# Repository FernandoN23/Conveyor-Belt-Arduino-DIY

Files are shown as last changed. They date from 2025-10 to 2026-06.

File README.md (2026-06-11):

# Conveyor Belt Arduino DIY V2🏗️🤖






*Author: Fernando Navarrete* ✍️

---

## English Version 🇺🇸

### 🌟 Project Overview
Welcome to the **Conveyor Belt Arduino DIY** master repository! This project details the multidisciplinary design, prototyping, and automation of an **Automatic Sorting Conveyor Belt** controlled by an Arduino microcontroller.

The machine scans physical objects inside a darkened chamber using a **TCS3200 (GY-31) Color Sensor**, maps raw optical readings into standard RGB values, and commands electromechanical actuators to split the materials into different receiving bins.

---

### 🚀 What's New in Version 2 (V2 Updates)
The system has been completely overhauled from the previous V1 baseline to meet the technical requirements of **Mechatronics Challenge 2**. 

* **Ergonomic CAD Redesign:** Structural components were re-engineered for simpler, faster physical assembly, optimized alignment tolerances, and enhanced overall rigidity.
* **Custom PCB Centralization:** Point-to-point breadboard/jumper wiring was eliminated. A dedicated green PCB with high-contrast yellow silkscreen was engineered in EasyEDA, introducing an **LM2596 DC-DC Buck Regulator** for 5V stability, a **470µF filter capacitor** to buffer servo spikes, and modular XH2.54 connector rails.
* **Worm Gear Power Transmission:** The V1 DC motor was upgraded to a high-torque **NEMA 17 Stepper Motor** driven by an **EasyDriver A3967**. Power transfer is achieved via an integrated printed worm screw (*tornillo helicoidal*) and a custom gear pulley, preventing unintended belt slides via mechanical irreversibility.
* **Innovative TPU Timing Belt:** Implemented a lightweight, continuous V-trapezoidal timing belt printed locally in two separate flexible **TPU** parts and bonded with high-strength cyanoacrylate. Testing validated that this bond does not compromise tensile strength, allowing a 100% printed internal drive loop (leaving only the clear acrylic side walls for structural visibility).

#### 🔮 Future Enhancements & Roadmap
* **Electrical Noise Isolation:** Reroute the PCB traces into a V3 revision with a dedicated, star-grounded row of free `GND` headers to isolate stepper power returns from the sensitive Arduino logic lines.
* **Industrial Belt Upgrade:** Transition from the current custom-printed TPU belt to an off-the-shelf industrial síncrona timing belt to enhance continuous operation lifespans.

---

## Versión en Español 🇪🇸

### 🌟 Resumen del Proyecto
¡Bienvenido al repositorio maestro **Conveyor Belt Arduino DIY**! Este proyecto detalla el diseño multidisciplinario, prototipado y automatización de una **Cinta Transportadora Clasificadora Automática** controlada por un microcontrolador Arduino.

El sistema escanea objetos físicos dentro de una cámara oscura mediante un **Sensor de Color TCS3200 (GY-31)**, mapea las lecturas ópticas crudas a valores RGB estándar y comanda actuadores electromecánicos para desviar las piezas hacia sus respectivos depósitos de clasificación.

---

### 🚀 Novedades de la Versión 2 (Actualizaciones V2)
El sistema ha sido completamente rediseñado desde la base de la versión V1 para cumplir con los exigentes requerimientos técnicos del **Desafío 2 de Mecatrónica**.

* **Rediseño Mecánico CAD:** Componentes estructurales optimizados para lograr un ensamblaje físico más simple, rápido y ergonómico, mejorando las tolerancias de alineación y la rigidez general del chasis.
* **Implementación de PCB Personalizada:** Se eliminó por completo el desorden de cables flotantes de la V1. Se diseñó una PCB verde con serigrafía amarilla en EasyEDA, incorporando un regulador **Buck DC-DC LM2596** para estabilizar el riel de 5V, un **condensador de filtro de 470µF** para absorber picos de los servos y filas de conectores modulares XH2.54 de conexión rápida.
* **Transmisión por Tornillo Sin Fin:** El motor DC convencional fue reemplazado por un **Motor Paso a Paso NEMA 17** de alto torque controlado por un driver **EasyDriver A3967**. La potencia se transmite mediante un tornillo helicoidal impreso y una polea corona engranada, dotando al sistema de irreversibilidad mecánica para evitar deslizamientos por inercia.
* **Correa Continua de TPU Impresa:** Se implementó una correa delgada trapezoidal tipo *timing belt* impresa localmente en dos partes de **TPU** flexible, unidas firmemente con cianoacrilato (*gotita*). Las pruebas de laboratorio demostraron que esta unión no compromete la resistencia a la tracción (aguanta una carga considerable), logrando que casi todo el mecanismo sea impreso (excepto las paredes de acrílico claro).

#### 🔮 Mejoras a Futuro y Hoja de Ruta
* **Aislamiento de Ruido Eléctrico:** Reconfigurar el ruteo de pistas para una revisión V3 incorporando filas de pines `GND` libres en una distribución de tierra en estrella, aislando los retornos de potencia del motor de las líneas lógicas del Arduino.
* **Correa Industrial Síncrona:** Reemplazar a futuro la correa de TPU impresa por una correa síncrona industrial comercial (adquirida externamente) para maximizar los ciclos de trabajo continuo.

---

## 📚 Documentation & Modules / Documentación y Módulos

Explore the directories below for detailed technical documentation on the current V2 standard and legacy V1 history.
*Explora los directorios a continuación para revisar la documentación técnica de la versión V2 actual y el historial heredado de la V1.*

| Module / Módulo | Description / Descripción |
| :--- | :--- |
| **📦 [Bill of Materials (BOM) / Lista de Materiales](./Conveyor-Belt-Arduino-V2/BOM%20v2/README.md)** | **V2 Purchase List & Printed Weights.** <br>Complete catalog of current hardware (NEMA 17, EasyDriver, LM2596, custom PCB) and empty weight fields for 3D printed parts.<br>---<br>**Lista de Compra y Pesos V2.**<br>Catálogo completo de hardware actual (NEMA 17, EasyDriver, LM2596, PCB) y espacios para rellenar los gramos de las piezas impresas. |
| **📐 [CAD Design Files / Archivos de Diseño CAD](./Conveyor-Belt-Arduino-V2/CAD%20v2/README.md)** | **Source Models (Fusion 360 & STEP V2).** <br>Download the digital twin organized into `/Electronic Parts`, `/Mechanic Parts`, and custom `/Parts` sub-folders.<br>---<br>**Modelos Fuente (Fusion 360 y STEP V2).**<br>Descarga el gemelo digital organizado en subcarpetas de componentes electrónicos, mecánicos y piezas personalizadas. |
| **🔦 [Acrylic Manufacturing / Manufactura de Acrílico](./Conveyor-Belt-Arduino-V1/Acrylic%20Wall%20Manufacturing/README.md)** | **Laser Cutting Files (Legacy/Reference).** <br>Production layouts (`.dxf`, `.beam`) for the transparent 4mm side walls critical for housing structural integrity.<br>---<br>**Archivos de Corte Láser (Referencia).**<br>Planos de producción (`.dxf`, `.beam`) para las paredes laterales de acrílico transparente de 4mm, críticas para la estructura. |
| **⚡ [Electronics & Wiring / Cableado y Electrónica](./Conveyor-Belt-Arduino-V2/Electronics%20v2/README.md)** | **PCB Schematics & Gerber Layouts.** <br>Contains the EasyEDA schematic sheets, trace distribution dimensions (0.4mm/0.6mm), and `Gerber_Files_V2.zip` production archives.<br>---<br>**Esquemas de PCB y Archivos Gerber.**<br>Contiene los esquemas de EasyEDA, anchos de pista lógicos/potencia (0.4mm/0.6mm) y el comprimido de producción `Gerber_Files_V2.zip`. |
| **💻 [Software & Logic / Programación y Lógica](./Conveyor-Belt-Arduino-V2/Code%20v2/README.md)** | **AccelStepper Firmware V2.** <br>Source code (`.ino`) incorporating `AccelStepper` non-blocking ramps, sensor mapping functions, and hardware protection angle clamps.<br>---<br>**Firmware AccelStepper V2.**<br>Código fuente (`.ino`) que incorpora control de rampas no bloqueantes con `AccelStepper`, mapeo del sensor y límites de seguridad angular. |
| **📸 [Multimedia Gallery / Galería Multimedia](./Multimedia/README.md)** | **Renders & Visuals.** <br>High-quality digital Twin renders, workbench photos, and operational video reels of the final sorting system.<br>---<br>**Renders y Visuales.**<br>Renders de alta calidad del gemelo digital, capturas del banco de pruebas y videos de operación del sistema clasificador. |

---

## 🎓 Acknowledgments / Agradecimientos

This project was made possible thanks to the academic support and specialized fabrication facilities provided by the **University of Chile**.

*Este proyecto fue posible gracias al apoyo académico y las instalaciones de fabricación especializadas provistas por la **Universidad de Chile**.*

| Institution / Institución | Contribution / Contribución |
| :---: | :--- |
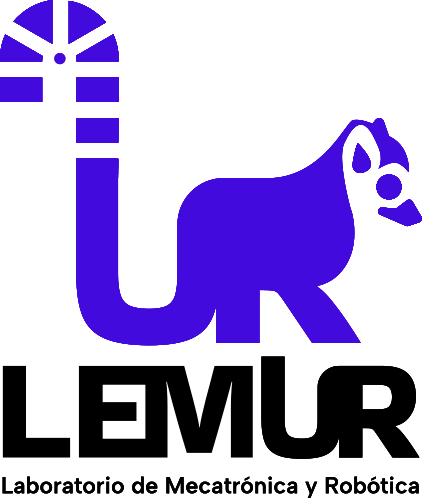
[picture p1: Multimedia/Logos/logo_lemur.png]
LEMUR Logo
|  | **LEMUR (Laboratorio de Ingeniería Mecatrónica y Robótica)**<br>For providing the specialized engineering workspace, FDM 3D printers, and test instrumentation required for the belt validation.<br>*(Por proveer el espacio de ingeniería, impresoras 3D FDM e instrumentación de prueba necesaria para la validación de la correa).* |
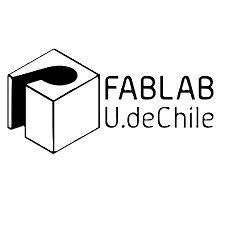
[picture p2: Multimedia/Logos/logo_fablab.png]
FabLab Logo
|  | **FABLAB U. de Chile**<br>For their technical manufacturing advisory and access to computer-controlled machinery, specifically the Beambox Series Pro laser cutter.<br>*(Por su asesoría técnica en manufactura y el uso de maquinaria CNC, principalmente la cortadora láser Beambox Series Pro).* |

---
*Open Source Project - Mechatronics V2 Revision (2026)*

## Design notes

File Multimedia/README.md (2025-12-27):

# Conveyor Belt Arduino DIY - Multimedia Gallery 📸🎬

*Author: Fernando Navarrete* ✍️

## English Version 🇺🇸

Welcome to the **Multimedia** directory! 🖼️

This folder serves as the visual documentation hub for the **Sorting Conveyor Belt** project. Here you will find CAD renders, assembly diagrams, and in future updates, real-world photos and videos of the working prototype.

### 📂 Folder Structure

The visual assets are organized by project iteration:

```text
Multimedia
├── 📂 Logos
├── 📂 V1
│   ├── 📂 as_built  <-- Final conveyor belt multimedia
│   ├── 🖼️ Ensamble Correa Transportadora ISO.png
│   ├── 🖼️ Ensamble Correa Transportadora Oruga Interior.png
│   ├── ... (Other render views)
│   └── 🖼️ Ensamble_ISO_Black_background.png
└── 📝 README.md                    <-- (Documentation) You are here

```

---

### 🏗️ Version 1 (V1) - CAD Design

This section documents the first iteration of the mechanism. The images below represent the **3D Modeling and Rendering** phase, used to validate geometry, mechanical tolerances, and component layout before physical manufacturing.

> **Note:** These images represent the virtual environment. Photos of the physical assembly will be added in a later stage inside a `/Real_Photos` directory.

#### 🌟 Hero View (Studio Render)

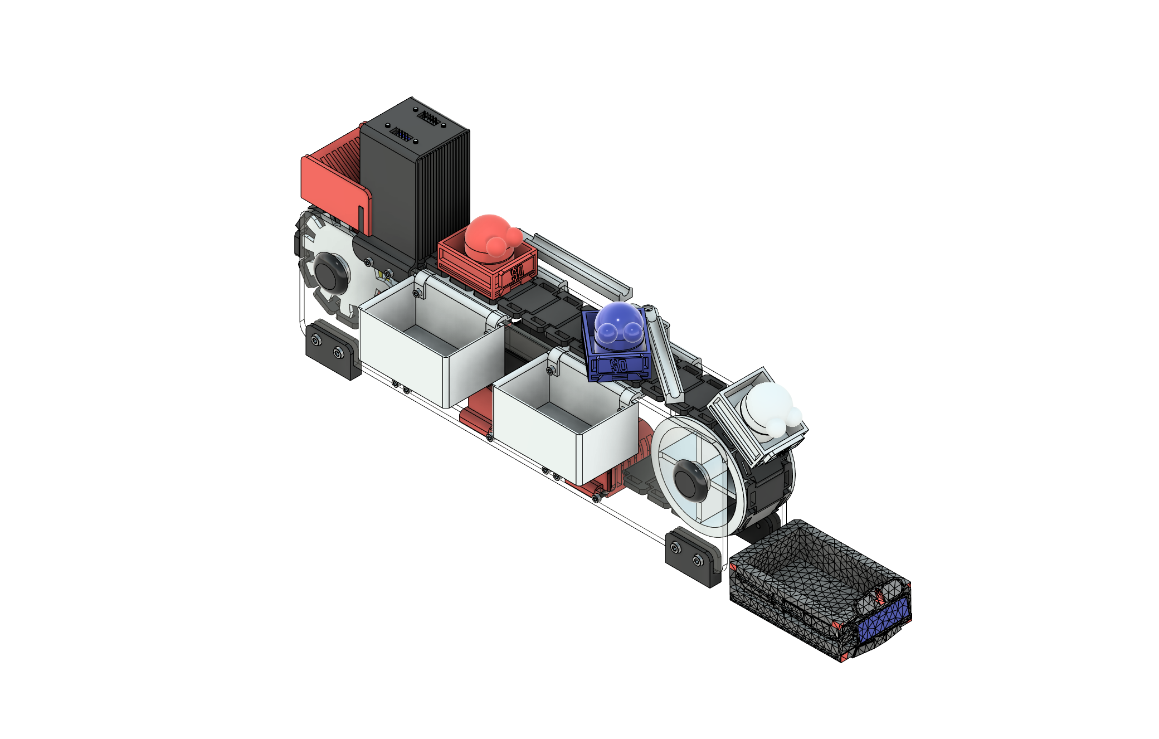
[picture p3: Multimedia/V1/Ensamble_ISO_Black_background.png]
Vista Hero


#### 📐 Technical Views & Assembly

Below is a gallery of different perspectives of the mechanical design, including isometric, top, and profile views to assist in understanding the structure.

| Isométrica General | Isométrica Alternativa |
| :---: | :---: |
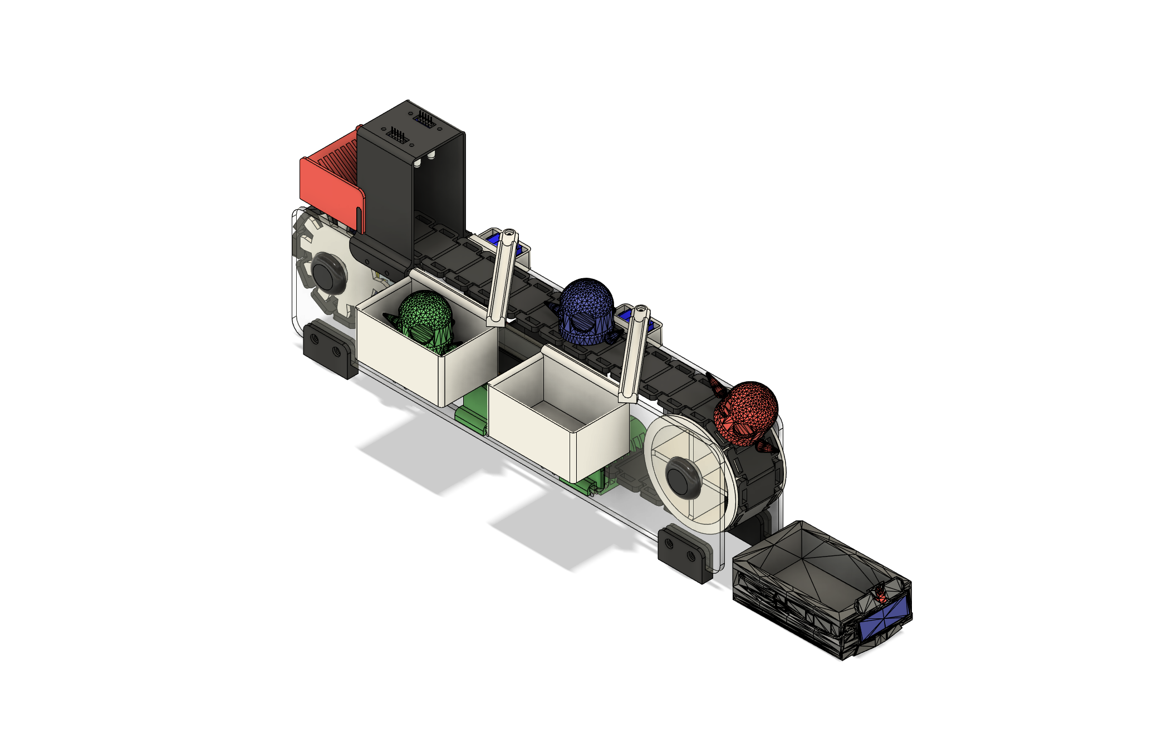
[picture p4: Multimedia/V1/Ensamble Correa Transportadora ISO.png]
Iso 1
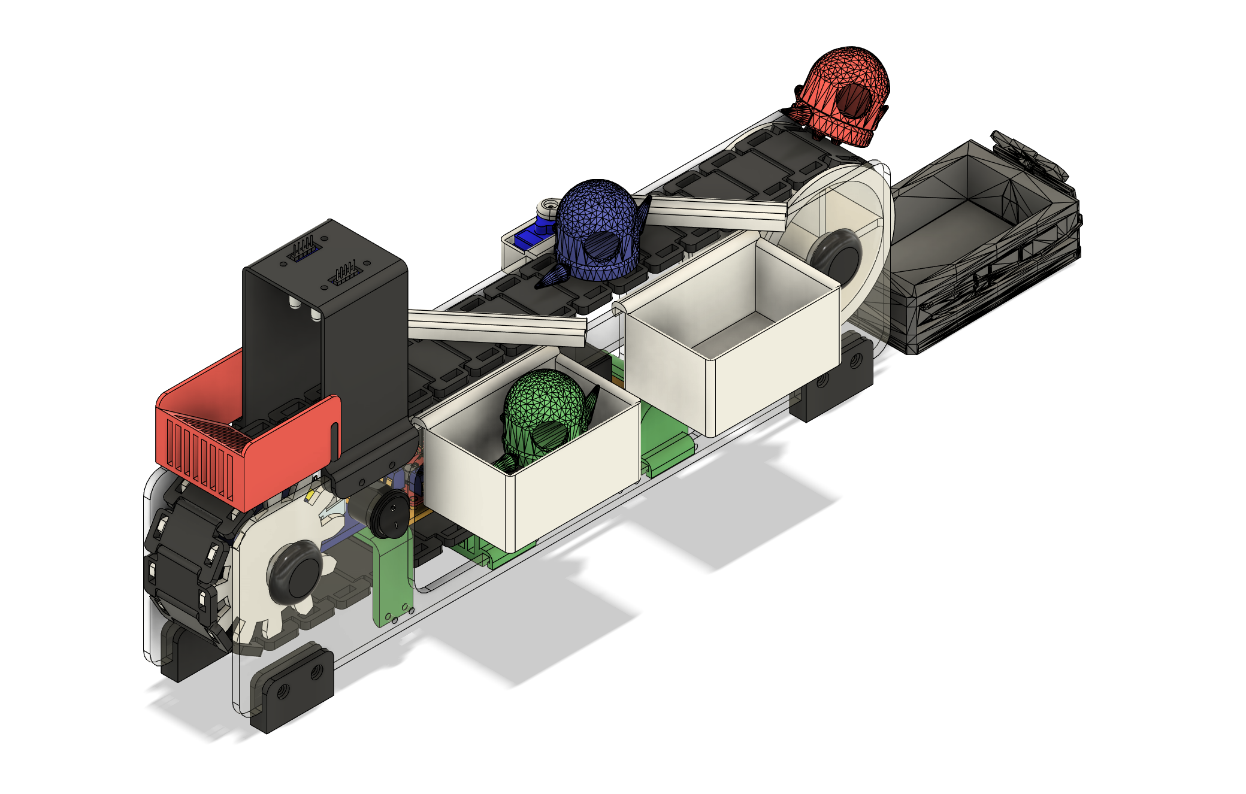
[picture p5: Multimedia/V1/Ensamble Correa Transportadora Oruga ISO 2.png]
Iso 2
|  |  |

| Vista de Planta (Superior) | Vista Lateral (Perfil) |
| :---: | :---: |
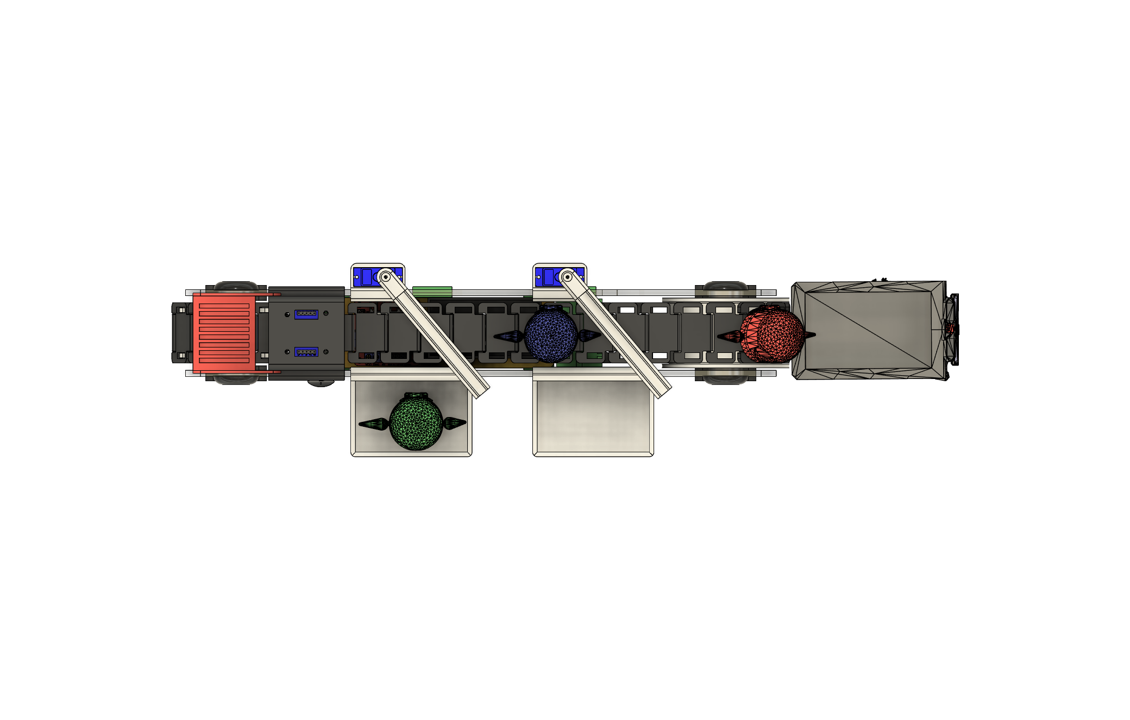
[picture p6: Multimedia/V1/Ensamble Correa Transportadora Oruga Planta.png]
Planta
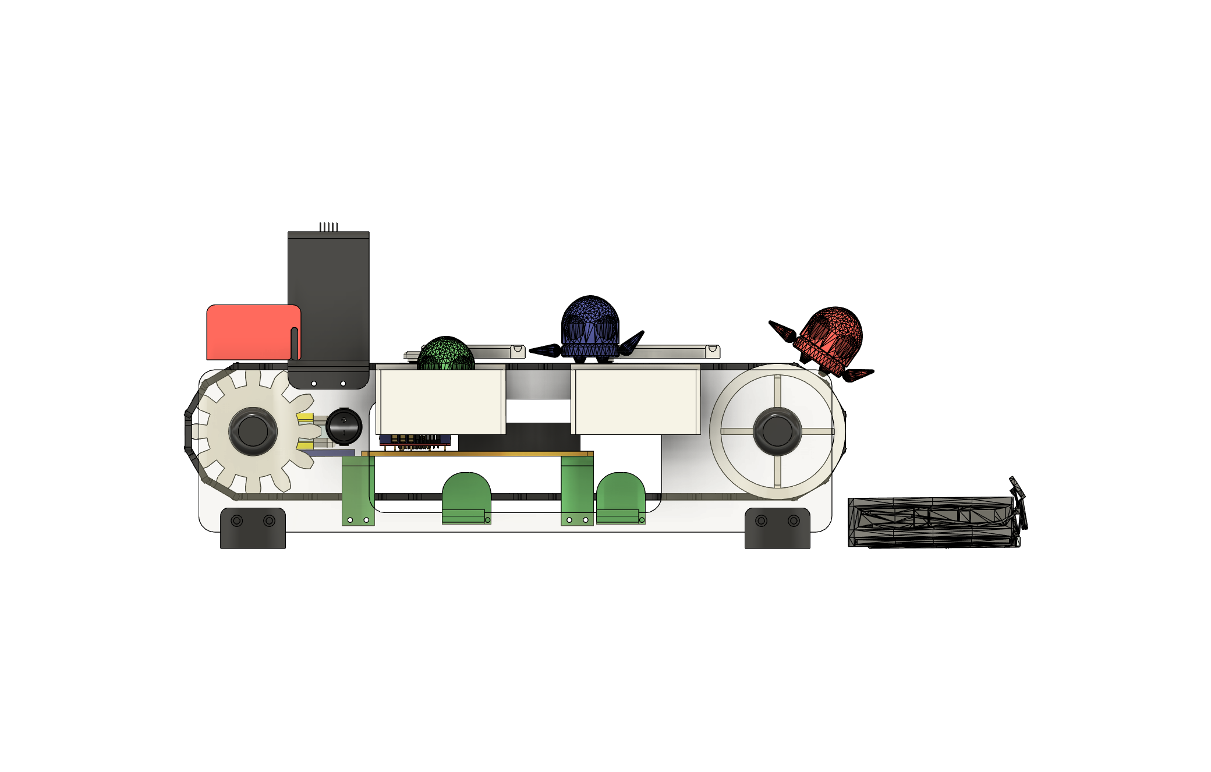
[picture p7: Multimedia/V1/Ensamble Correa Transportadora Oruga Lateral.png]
Lateral
|  |  |

#### ⚙️ Mechanical Detail: Internal Track System

Focus on the internal arrangement of pulleys and transmission.

| Internal Mechanism |
| --- |
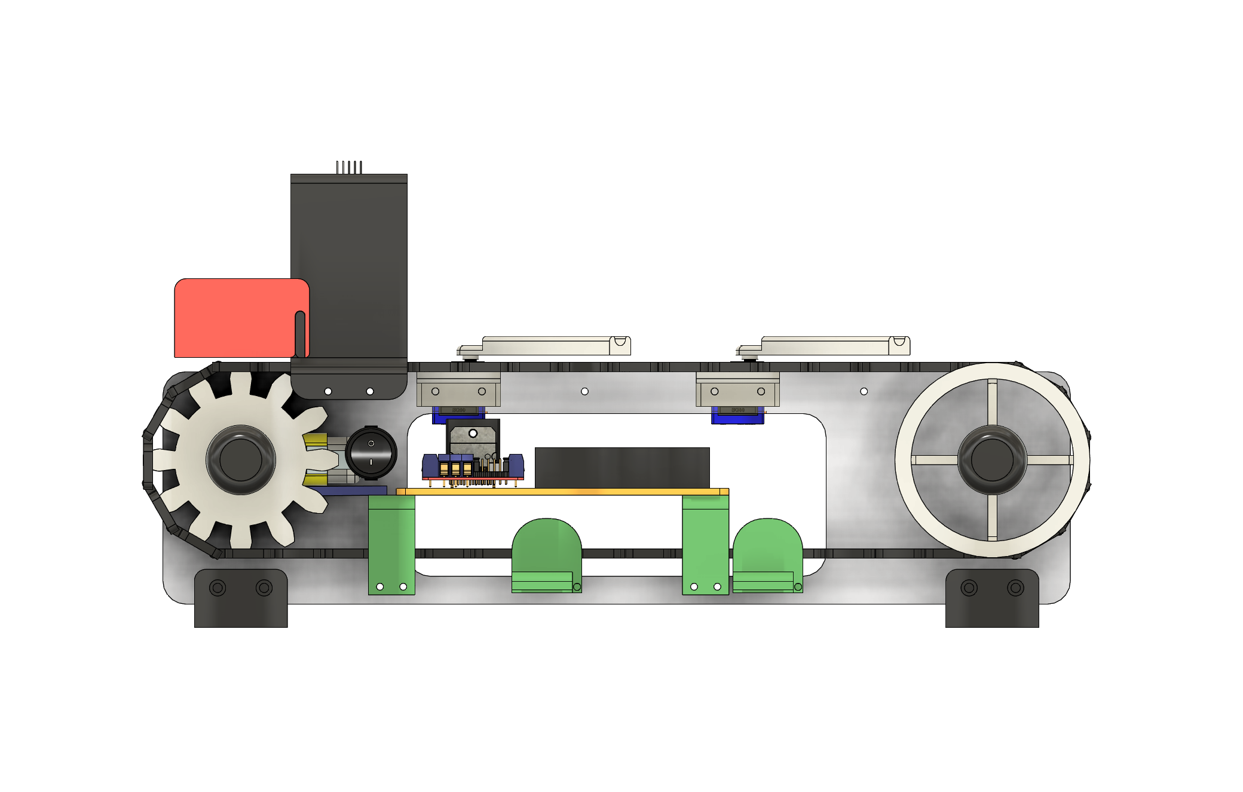
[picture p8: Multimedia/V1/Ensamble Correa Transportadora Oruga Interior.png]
Interior
|  |

> **⚠️ Mechanical Note on Tolerances:**
> Due to the necessary design clearances (tolerances) in the CAD model, **belt tensioners are not shown in their active operational state** in these renders.
> However, for the physical assembly, tensioners are **mandatory** to ensure proper friction and movement of the belt.

---

## Versión en Español 🇪🇸

*Autor: Fernando Navarrete* ✍️

¡Bienvenido al directorio **Multimedia**! 🖼️

Esta carpeta sirve como el centro de documentación visual para el proyecto de la **Cinta Transportadora Clasificadora**. Aquí encontrarás renders del diseño, diagramas de ensamblaje y, en futuras actualizaciones, fotografías reales y videos del prototipo en funcionamiento.

### 📂 Estructura de Carpetas

Los recursos visuales están organizados por iteración del proyecto:

```text
Multimedia
├── 📂 Logos
├── 📂 V1
│   ├── 📂 as_built  <-- Multimedia final correa transportadora
│   ├── 🖼️ Ensamble Correa Transportadora ISO.png
│   ├── 🖼️ Ensamble Correa Transportadora Oruga Interior.png
│   ├── ... (Otras vistas renderizadas)
│   └── 🖼️ Ensamble_ISO_Black_background.png
└── 📝 README.md                    <-- (Documentación) Estás aquí

```

---

### 🏗️ Versión 1 (V1) - Diseño CAD

Esta sección documenta la primera iteración del mecanismo. Las imágenes presentadas a continuación corresponden a la fase de **Modelado 3D y Renderizado**, utilizadas para validar la geometría, las tolerancias mecánicas y la disposición de componentes antes de la manufactura física.

> **Nota:** Estas imágenes representan el entorno virtual. Las fotografías del ensamblaje físico se añadirán en una etapa posterior dentro de un directorio `/Real_Photos`.

#### 🌟 Vista Principal (Render de Estudio)

Vista Hero

#### 📐 Vistas Técnicas y de Ensamblaje

A continuación se presenta una galería con diferentes perspectivas del diseño mecánico, incluyendo vistas isométricas, de planta y de perfil para facilitar la comprensión de la estructura.

| Isométrica General | Isométrica Alternativa |
| :---: | :---: |
| Iso 1 | Iso 2 |

| Vista de Planta (Superior) | Vista Lateral (Perfil) |
| :---: | :---: |
| Planta | Lateral |

#### ⚙️ Detalle Mecánico: Sistema de Oruga Interior

Enfoque en la disposición interna de poleas y transmisión.

| Mecanismo Interno |
| --- |
| Interior |

> **⚠️ Nota Mecánica sobre Tolerancias:**
> Debido a las holguras de diseño necesarias en el modelo CAD, **los tensores de la correa no se muestran en su estado operativo de tensión** en estos renders.
> Sin embargo, para el ensamblaje físico, los tensores son **obligatorios** para asegurar la fricción y el movimiento correcto de la banda.

---

## 🛠️ Fabrication & As-Built (V1) / Fabricación y Prototipo Real

**🇬🇧 English:**
This section showcases the **physical realization** of the project. These photos demonstrate the final assembly using 3D printed parts, acrylic supports, and the electronic integration.

**🇪🇸 Español:**
Esta sección muestra la **realización física** del proyecto. Estas fotos demuestran el ensamblaje final utilizando piezas impresas en 3D, soportes de acrílico y la integración electrónica.

### 📸 Final Assembly / Ensamblaje Final

| Front View / Vista Frontal | Side View / Vista Lateral |
| ----- | ----- |
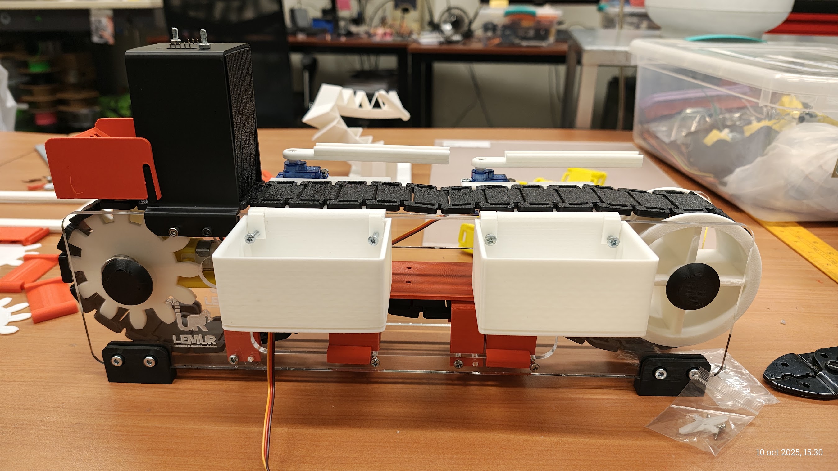
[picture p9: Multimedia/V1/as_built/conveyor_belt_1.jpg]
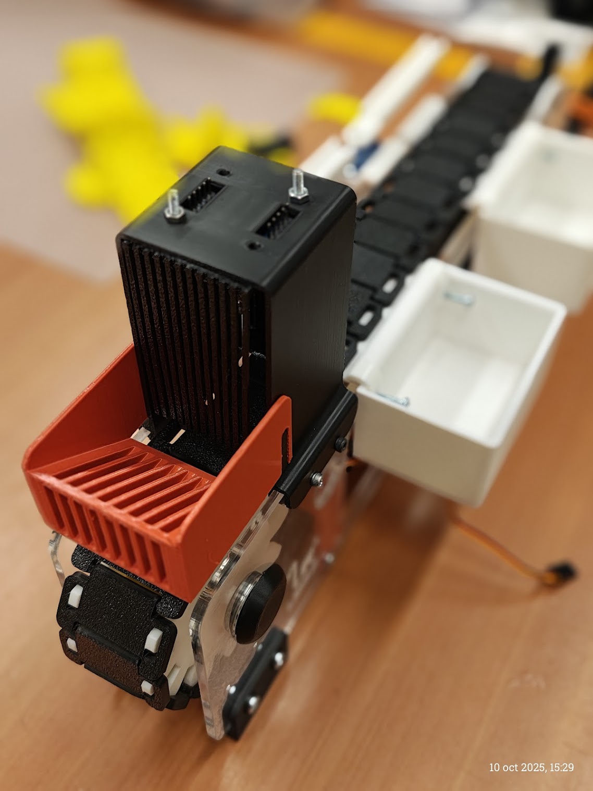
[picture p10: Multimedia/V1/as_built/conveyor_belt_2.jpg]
|  |  |

### 🔧 Fabrication Details / Detalles de Fabricación

| Fabrication / Fabricación | Acrylic Wall / Pared Acrílica | Release / Estreno |
| ----- | ----- | ----- |
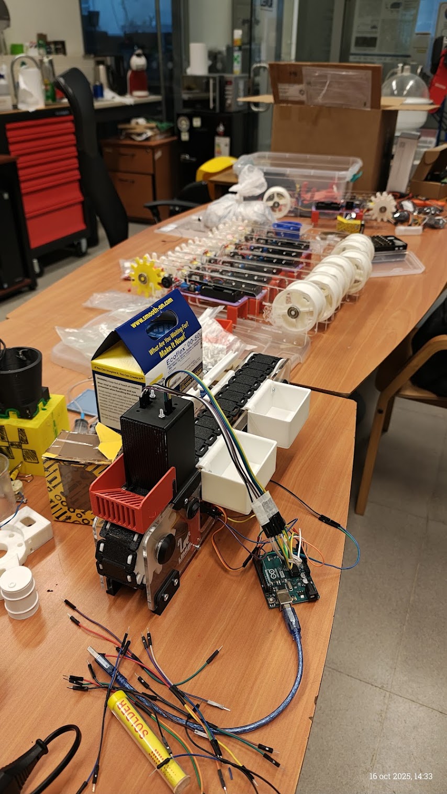
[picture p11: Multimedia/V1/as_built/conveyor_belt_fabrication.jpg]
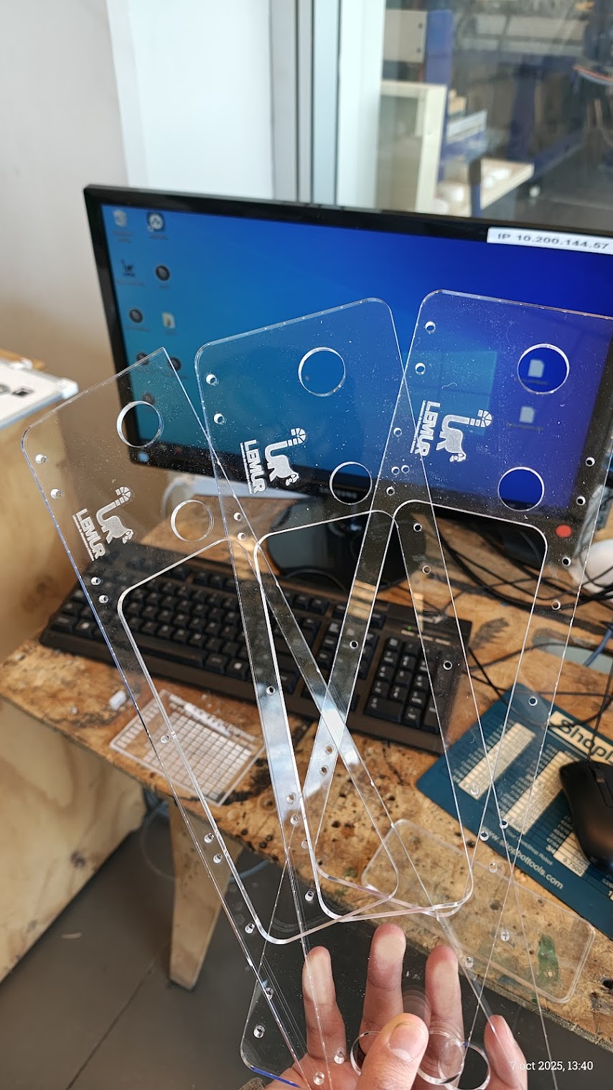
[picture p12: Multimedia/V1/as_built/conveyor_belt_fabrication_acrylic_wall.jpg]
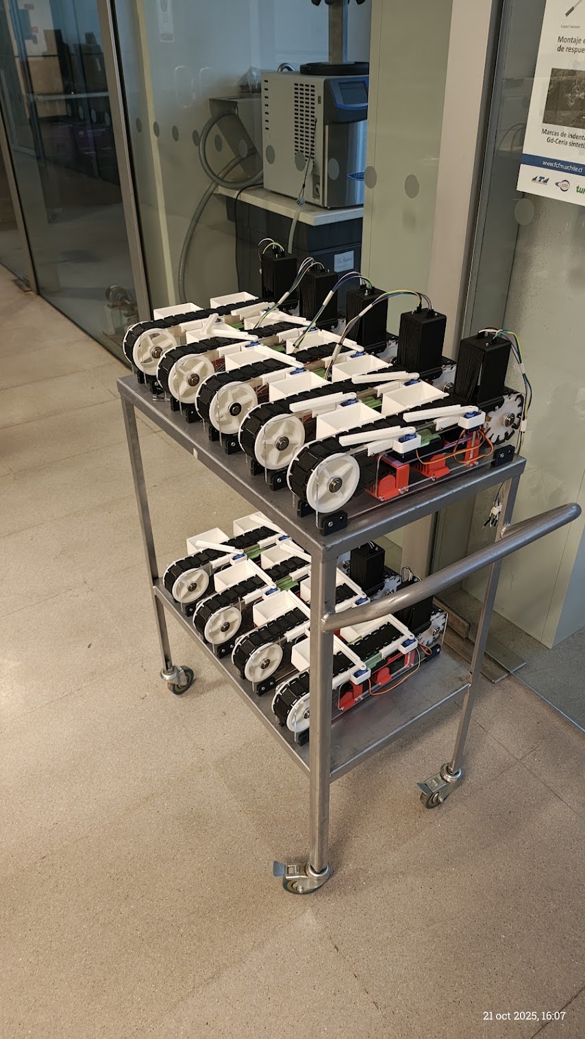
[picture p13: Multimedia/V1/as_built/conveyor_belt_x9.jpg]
|  |  |  |

---
*Happy Coding & Building!* 🚀

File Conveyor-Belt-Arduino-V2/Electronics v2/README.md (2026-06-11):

# Conveyor Belt Arduino DIY - Electronics & Wiring ⚡🔌

*Author: Fernando Navarrete* ✍️

## English Version 🇺🇸

Welcome to the **Electronics v2** directory! 🔋

This section covers the physical "nervous system" and custom circuit architecture of the **Sorting Conveyor Belt V2**. In this version, standard point-to-point jumper routing has been replaced by a **Custom Printed Circuit Board (PCB)** to enhance structural reliability, mitigate electromagnetic interference (EMI), and centralize modular connections.

### 📂 Available Manufacturing Files
Inside this directory, you will find the required hardware manufacturing and project files:
* 📁 **`Gerber_Files_V2.zip`**: Complete set of production photoplotter files in standard Gerber RS-274X format for physical CNC milling or external PCB manufacturing.
* 📦 **`Project_EasyEDA_V2.zip`**: Native source project package compatible with EasyEDA for hardware modifications, schematic tuning, and trace rerouting.

### 📜 Component Checklist
These are the core electronic components integrated into the custom board design:
* **Microcontroller:** Arduino Uno/Nano (The central logic processing unit).
* **Actuators:**
    * 1x NEMA 17 Stepper Motor (Main precise drive unit).
    * 1x EasyDriver A3967 Module (Microstepping driver).
    * 2x SG90 Servomotors (Sorting dynamic gates).
* **Sensors:**
    * 1x TCS3200 / GY-31 (RGB Color Sensor).
* **Power Regulation & Protection:**
    * 3x 18650 Li-Ion Batteries (~11.1V - 12.6V input power rail).
    * 1x LM2596 DC-DC Step-Down Buck Converter Module (Logic voltage regulator).
    * 1x 470µF Electrolytic Capacitor (De-coupling/filter layout element).
    * 1x SPST 2-Pin Toggle Switch.

---

### 🗺️ Electronic Diagram & PCB Specs

> **📄 VIEW DIAGRAM:**
> Please open the attached schematic PDF file **`Esquematico_Desafio_2_ME4250.pdf`** located in this folder to examine the component nets, footprint callouts, and internal routing sheets.

* **PCB Physical Spec Constraints:** * **Solder Mask color:** Industrial Green with high-contrast Yellow silkscreen labeling for clear pinout identification and project credits.
  * **Vias and Drill holes:** Standard logic size (0.254 mm / 10 mil).
  * **Trace Widths:** Standard signal/logic traces are routed at **0.4 mm**. Current-heavy Power traces (VCC, Motor outputs, and Regulator pins) are widened to **0.6 mm** to withstand step transients without heating.

---

### 🔌 Wiring Guide & Pinout Mapping

Ensure your modular cable harnesses (using XH2.54 terminal pins) match this hardware definition matrix embedded into the custom board layout:

| Component | Schematic Pin Label | Arduino Pin Connection | Description |
| :--- | :--- | :---: | :--- |
| **EasyDriver A3967** | STEP | **D2** | Step Pulse Command Signal |
| | DIR | **D3** | Direction Control Level |
| **TCS3200 (GY-31)** | S0, S1 | **A0, A1** | Output Frequency Scaling |
| | S2, S3 | **A2, A3** | Photodiode Color Array Selection |
| | OUT | **D4** | Frequency Pulse Width Input |
| **Servos (SG90)** | PWM_SG90_1 | **D9** | Gate 1 Actuator Control Signal |
| | PWM_SG90_2 | **D10** | Gate 2 Actuator Control Signal |

---

### ⚠️ Critical Engineering Design Note: Common Ground Anomalies

> **🛠️ POST-MORTEM HARDWARE OBSERVATION:**
> During the layout routing of the `Desafio_2_v2` schematic, a minor design discrepancy was introduced regarding the logic return path:
> * **The Issue:** The main `GND` network connection back to the Arduino microcontroler was bridged through a terminal pin assigned directly to the **LM2596 regulator block** instead of establishing a separate, noise-isolated digital ground pin on the main microcontroler header.
> * **Behavioral Impact:** Although electrical continuity is sustained globally across the negative terminal of the 18650 battery pack, heavy return currents from the stepper driver switching stages can couple electrical switching noise onto the sensitive analog/digital ground lines of the microcontroller.
> * **Future Iterations V3 Requirement:** Future engineering remakes must integrate a dedicated, independent row of free `GND` distribution headers linked via a clean star-ground layout geometry to safeguard signal integrity.

---

## Versión en Español 🇪🇸

*Autor: Fernando Navarrete* ✍️

¡Bienvenido al directorio **Electronics v2**! 🔋

Esta sección cubre el "sistema nervioso" físico y la arquitectura de circuitos de la **Cinta Transportadora Clasificadora V2**. En esta versión, el cableado por jumpers punto a punto ha sido reemplazado por una **Placa de Circuito Impreso (PCB) Personalizada** para mejorar la confiabilidad estructural, mitigar la interferencia electromagnética (EMI) y centralizar los acoples modulares.

### 📂 Archivos de Manufactura Disponibles
Dentro de este directorio, se encuentran los archivos necesarios para la fabricación del hardware:
* 📁 **`Gerber_Files_V2.zip`**: Conjunto de archivos de fotoploteo de producción en formato estándar Gerber RS-274X para el fresado CNC físico o manufactura externa de la PCB.
* 📦 **`Project_EasyEDA_V2.zip`**: Paquete nativo del proyecto compatible con EasyEDA para modificaciones de hardware, edición de esquemáticos y ruteo de pistas.

### 📜 Lista de Verificación de Componentes
Estos son los componentes electrónicos principales integrados en el diseño de la placa personalizada:
* **Microcontrolador:** Arduino Uno/Nano (Unidad de procesamiento lógico central).
* **Actuadores:**
    * 1x Motor Paso a Paso NEMA 17 (Unidad principal de tracción de precisión).
    * 1x Módulo Driver EasyDriver A3967 (Controlador de micropasos).
    * 2x Servomotores SG90 (Aletas dinámicas de clasificación).
* **Sensores:**
    * 1x TCS3200 / GY-31 (Sensor de Color RGB).
* **Regulación de Energía y Protección:**
    * 3x Baterías Li-Ion 18650 (Línea de potencia de entrada de ~11.1V - 12.6V).
    * 1x Regulador Convertidor Buck DC-DC Step-Down LM2596 (Regulador de voltaje lógico a 5V).
    * 1x Condensador Electrolítico de 470µF (Elemento de filtrado y desacople en la línea).
    * 1x Interruptor SPST de 2 pines.

---

### 🗺️ Diagrama Electrónico y Especificaciones de la PCB

> **📄 VER DIAGRAMA:**
> Por favor, abre el archivo PDF adjunto **`Esquematico_Desafio_2_ME4250.pdf`** en esta carpeta para examinar las redes de componentes, los encapsulados y los planos de ruteo interno.

* **Restricciones Técnicas de la PCB:** * **Color de Antisolder:** Verde industrial con serigrafía amarilla de alta definición para la identificación de pines, componentes y créditos del desarrollador.
  * **Vias y Perforaciones (Drills):** Tamaño estándar para señales lógicas (0.254 mm / 10 mil).
  * **Ancho de Pistas:** Las pistas estándar de señal lógica están ruteadas a **0.4 mm**. Las líneas de potencia que manejan alta corriente (VCC, salidas de motor y pines del regulador) se ensancharon a **0.6 mm** para soportar transitorios de corriente sin calentamiento del cobre.

---

### 🔌 Guía de Cableado y Mapa de Pines (Pinout)

Asegúrate de que los arneses de cables modulares (usando terminales XH2.54) coincidan con esta matriz de definición de hardware grabada en el diseño de la PCB:

| Componente | Etiqueta de Pin | Conexión Pin Arduino | Descripción |
| :--- | :--- | :---: | :--- |
| **EasyDriver A3967** | STEP | **D2** | Señal de Comando de Pulso de Paso |
| | DIR | **D3** | Nivel de Control de Dirección |
| **TCS3200 (GY-31)** | S0, S1 | **A0, A1** | Escalamiento de Frecuencia de Salida |
| | S2, S3 | **A2, A3** | Selección de Matriz de Fotodiodos de Color |
| | OUT | **D4** | Entrada de Ancho de Pulso de Frecuencia |
| **Servos (SG90)** | PWM_SG90_1 | **D9** | Señal de Control Actuador Aleta 1 |
| | PWM_SG90_2 | **D10** | Señal de Control Actuador Aleta 2 |

---

### ⚠️ Nota Crítica de Ingeniería: Anomalía de Tierra Común

> **🛠️ OBSERVACIÓN DE REVISIÓN DE HARDWARE:**
> Durante el ruteo de las pistas del esquemático `Desafio_2_v2`, se introdujo una leve discrepancia de diseño en el camino de retorno lógico:
> * **El Problema:** La conexión de la red principal de `GND` hacia el Arduino quedó vinculada a través de un pin de terminal destinado directamente al **bloque del regulador LM2596**, en lugar de establecerse en un pin de tierra digital independiente y aislado en el header principal del Arduino.
> * **Impacto Conductual:** Aunque existe continuidad eléctrica global con el terminal negativo del pack de baterías 18650, las corrientes de retorno intensas de las etapas de conmutación del motor paso a paso pueden acoplar ruido eléctrico en las líneas de tierra lógicas del microcontrolador.
> * **Requerimiento para Futuras Iteraciones V3:** Los próximos rediseños deben integrar obligatoriamente una fila dedicada e independiente de pines headers de distribución `GND` conectados mediante una geometría de tierra en estrella (*star ground*) para salvaguardar la integridad de la señal.

---
*Safety First: Always double-check polarity and visual traces before switching on! / ¡Seguridad ante todo: revisa siempre la polaridad y las pistas visuales antes de encender!* 👷⚡

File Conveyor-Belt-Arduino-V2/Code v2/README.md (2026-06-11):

# Conveyor Belt Arduino DIY - Software & Logic 💻⚙️

*Author: Fernando Navarrete* ✍️

## English Version 🇺🇸

Welcome to the **Code v2** directory! 🧠

This folder contains the firmware required to operate the **Sorting Conveyor Belt V2**. The system utilizes an **Arduino** microcontroller to manage the high-precision logic of object detection, RGB color mapping, and electromechanical actuation using a stepper motor and servo barriers.

### 📂 Folder Structure

Here is the organization of the source files included in this version:

```text
Code v2
├── 📂 Calibration_TCS3200
│   └── 📜 Calibration_TCS3200.ino       <-- (Utility) Calibrate sensor min/max pulse width
├── 📜 Conveyor_Belt_D2_Student.ino      <-- (Main) Production code for sorting & evaluation (Desafío 2 Mecatrónica)
└── 📝 README.md                         <-- (Documentation) You are here

```

### 🔌 Pinout & Wiring

> **⚡ Electronic Diagram:**
> For detailed schematics, custom PCB routing paths, and power regulation connections, please visit the **Electronics v2** module:
> 👉 **[Electronics v2 README](https://www.google.com/search?q=../Electronics%2520v2/README.md)**

Below is the specific hardware pin mapping defined in the production source code (`Conveyor_Belt_D2_Student.ino`). Ensure your physical custom board connections strictly match these definitions to prevent hardware issues:

| Component | Pin Function | Arduino Pin | Notes |
| --- | --- | --- | --- |
| **EasyDriver A3967** | STEP | **D2** | Step pulse signal (AccelStepper Control) |
|  | DIR | **D3** | Direction control signal |
| **TCS3200 (GY-31)** | S0 | **A0** | Frequency Scaling Selection |
|  | S1 | **A1** | Frequency Scaling Selection |
|  | S2 | **A2** | Color Photodiode Filter Select |
|  | S3 | **A3** | Color Photodiode Filter Select |
|  | OUT | **D4** | Signal pulse width input (`pulseIn`) |
| **Servos** | Servo 1 | **D9** | Sorts objects (Safety constrained) |
|  | Servo 2 | **D10** | Sorts objects (Safety constrained) |

> **⚠️ Dependencies:** You must install the `AccelStepper.h` library via the Arduino Library Manager, and ensure `Servo.h` is available in your IDE environment before compiling.

### 🛠️ Execution Pipeline & Methodology

#### 1. Sensor Ambient Calibration (`Calibration_TCS3200.ino`)

Before running the main execution logic, you must determine the hardware frequency responses under your specific ambient light environment:

1. Upload `Calibration_TCS3200.ino` to your board.
2. Open the **Serial Monitor** at **115200 baud** (or the rate specified in calibration).
3. Place a **Matte Black** reference object under the sensor chamber and record the maximum pulse width times.
4. Place a **Pure White** reference object when prompted and record the minimum pulse width times.
5. **Note down the raw values** for the R, G, and B independent channels.

#### 2. Main Machine Operation (`Conveyor_Belt_D2_Student.ino`)

1. Open the primary production file: `Conveyor_Belt_D2_Student.ino`.
2. **Update the Calibration Bounds**: Navigate to the Step 2 configuration lines and input your logged values into the corresponding constants:
* `R_BLACK`, `G_BLACK`, `B_BLACK` (Long pulse width metrics).
* `R_WHITE`, `G_WHITE`, `B_WHITE` (Short pulse width metrics).

3. **Calibrate Sorting Logic thresholds**: Modify the conditional bounds inside `clasificarRGB(r, g, b)` to match your standard 0-255 mapped material profiles.
4. Upload the code to the microcontroller.
5. **System Sequence**:
* **Search Phase**: The belt moves in short, controlled increments (`400 steps`) searching for a payload.
* **Detection**: Upon valid color classification (Action $\neq$ 0), the mechanical safety code positions the sorting servos within structural limits ($45^\circ$ to $135^\circ$).
* **Dwell**: The mechanism waits for **5 seconds** after detection.
* **Evacuation**: The stepper drives the conveyor belt continuously for **10 seconds** (`50000 steps`) to clear the sorting zone.
* **Reset**: The conveyor stops safely and the servos automatically return to the safe rest alignment ($90^\circ$).

---

## Versión en Español 🇪🇸

*Autor: Fernando Navarrete* ✍️

¡Bienvenido al directorio **Code v2**! 🧠

Esta carpeta contiene el firmware necesario para operar la **Cinta Transportadora Clasificadora V2**. El sistema utiliza un microcontrolador **Arduino** para gestionar la lógica de alta precisión en detección de objetos, mapeo RGB de color y actuación electromecánica mediante un motor paso a paso y barreras de servomotores.

### 📂 Estructura de Carpetas

Aquí se muestra la organización de los archivos fuente incluidos en esta versión:

```text
Code v2
├── 📂 Calibration_TCS3200
│   └── 📜 Calibration_TCS3200.ino       <-- (Utilidad) Calibrar límites de ancho de pulso del sensor
├── 📜 Conveyor_Belt_D2_Student.ino      <-- (Principal) Código de producción para clasificación y evaluación (Desafío 2)
└── 📝 README.md                         <-- (Documentación) Estás aquí

```

### 🔌 Conexiones y Pinout

> **⚡ Diagrama Electrónico:**
> Para esquemas detallados, rutas de ruteo en la PCB personalizada y conexiones de regulación de potencia, por favor visita el módulo **Electronics v2**:
> 👉 **[Electronics v1 README](https://www.google.com/search?q=../Electronics%2520v2/README.md)**

A continuación se muestra el mapeo de hardware específico definido en el código fuente de producción (`Conveyor_Belt_D2_Student.ino`). Asegúrate de que tus conexiones físicas en la placa personalizada coincidan estrictamente con estas definiciones para evitar fallos de hardware:

| Componente | Función Pin | Pin Arduino | Notas |
| --- | --- | --- | --- |
| **EasyDriver A3967** | STEP | **D2** | Señal de pulsos de paso (Control AccelStepper) |
|  | DIR | **D3** | Señal de control de dirección |
| **TCS3200 (GY-31)** | S0 | **A0** | Selección de Escala de Frecuencia |
|  | S1 | **A1** | Selección de Escala de Frecuencia |
|  | S2 | **A2** | Selección Filtro de Fotodiodo de Color |
|  | S3 | **A3** | Selección Filtro de Fotodiodo de Color |
|  | OUT | **D4** | Entrada de ancho de pulso de señal (`pulseIn`) |
| **Servomotores** | Servo 1 | **D9** | Desvío de objetos (Restringido por seguridad) |
|  | Servo 2 | **D10** | Desvío de objetos (Restringido por seguridad) |

> **⚠️ Dependencias:** Debes instalar la librería `AccelStepper.h` a través del Gestor de Librerías de Arduino IDE, y verificar que `Servo.h` se encuentre disponible en tu entorno antes de compilar.

### 🛠️ Flujo Metodológico de Ejecución

#### 1. Calibración Ambiental del Sensor (`Calibration_TCS3200.ino`)

Antes de ejecutar la lógica de producción, es mandatorio determinar las respuestas en frecuencia del hardware bajo las condiciones lumínicas específicas del entorno:

1. Carga el archivo `Calibration_TCS3200.ino` en tu placa.
2. Abre el **Monitor Serie** configurado a **115200 baudios** (o la velocidad seteada en la utilidad).
3. Posiciona un objeto de referencia **Negro Mate** bajo la cámara oscura del sensor y registra los tiempos de ancho de pulso máximos.
4. Posiciona un objeto de referencia **Blanco Puro** cuando el sistema lo solicite y registra los tiempos de ancho de pulso mínimos.
5. **Anota los valores crudos** obtenidos para los canales independientes R, G y B.

#### 2. Operación de la Máquina Principal (`Conveyor_Belt_D2_Student.ino`)

1. Abre el archivo de producción principal: `Conveyor_Belt_D2_Student.ino`.
2. **Actualizar Límites de Calibración**: Dirígete a las líneas de configuración del Paso 2 e introduce los valores medidos en las constantes del firmware:
* `R_BLACK`, `G_BLACK`, `B_BLACK` (Métricas de tiempo para negro/tiempos largos).
* `R_WHITE`, `G_WHITE`, `B_WHITE` (Métricas de tiempo para blanco/tiempos cortos).

3. **Calibrar Umbrales de Clasificación**: Modifica las condiciones lógicas dentro de la función `clasificarRGB(r, g, b)` para que coincidan con los perfiles estándar mapeados (0-255) de tus objetos reales.
4. Carga el firmware modificado en el microcontrolador.
5. **Secuencia Dinámica**:
* **Fase de Búsqueda**: La correa avanza en pasos cortos controlados (`400 pasos`) buscando variaciones en el sensor.
* **Detección**: Al clasificar un color válido (Acción $\neq$ 0), el filtro de protección mecánica posiciona los servos dentro de rangos seguros ($45^\circ$ a $135^\circ$) previniendo colisiones mecánicas con el chasis.
* **Espera**: El proceso realiza un retraso controlado de **5 segundos** posterior a la detección.
* **Evacuación**: El motor paso a paso tracciona de forma continua durante **10 segundos** (`50000 pasos`) para despachar el objeto hacia su respectiva caja receptora.
* **Restablecimiento**: La correa se detiene con una rampa desacelerada y las palas retornan automáticamente a su ángulo seguro de descanso ($90^\circ$).

---

*Happy Coding & Building!* 🚀

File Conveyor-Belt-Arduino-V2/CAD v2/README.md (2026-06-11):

# Conveyor Belt Arduino DIY - CAD Models 📐🤖

*Author: Fernando Navarrete* ✍️

## English Version 🇺🇸

Welcome to the **Digital Design Repository** for the **REPOS Sorting Conveyor Belt V2**!

This directory contains the source files for the mechanical structure. Whether you want to modify the design or simply export files for 3D printing, you will find everything you need here.

### 📂 1. Available File Formats
We provide the models in two industry-standard formats to ensure compatibility with your preferred CAD software.

| Format | Extension | Description | Recommended Use |
| :--- | :---: | :--- | :--- |
| **Fusion 360** | `.f3d` | **Native Source Files.** Contains the full design history and parametric timeline. | Best for **editing**, modifying dimensions, or remixing the project using Autodesk Fusion 360. |
| **STEP** | `.step` | **Universal Exchange Format.** Standard 3D model format without design history. | Best for importing into **SolidWorks, Inventor, Rhino, Onshape**, or slicers. |

### 🗂️ 2. Directory Structure

> **📍 NAVIGATION TIP:**
> The files are organized by format. Choose the folder that matches your software workflow: `../Fusion360` or `../STEP`.

Inside each format folder, you will find the following organized hierarchy:

* 📄 **`Ensamble Correa Transportadora Miniatura`** (Main Assembly File):
    * This is the **Full Assembly**. It contains the entire machine fully integrated. Use this file to understand how parts fit together, check clearances, or view the complete digital twin.
* 📁 **`/Electronic Parts`** (Sub-folder):
    * Contains CAD models of the active electromechanical and electronic hardware (e.g., *NEMA 17 Stepper Motor*, *EasyDriver A3967*, *Arduino*, *SG90 Servos*, *Custom PCB*). Use these for dimensional references and housing fitment checks.
* 📁 **`/Mechanic Parts`** (Sub-folder):
    * Contains CAD models of standard mechanical hardware (e.g., *627zz Bearings*, *Neodymium Magnets*, *M3/M4 Bolts*). Essential for checking fastener clearances.
* 📁 **`/Parts`** (Sub-folder):
    * Contains **Individual Custom Mechanical Components** designed specifically for this project (e.g., *Worm Screw*, *Gear Pulley*, *Chamber*, *Boxes*).
    * **Use these files for 3D Printing:** Open the individual components in this folder to export them as `.stl` or `.3mf` for your slicer software.

### ⚠️ Important Manufacturing Notes

* **Acrylic Side Walls:** The files named `Soportes_Acrilico` are included here for assembly reference only. **DO NOT 3D PRINT THESE PARTS.** They are designed for Laser Cutting (4mm Acrylic).
    * 👉 **For production files (`.dxf`, `.beam`) and laser parameters, please refer to the [Acrylic Wall Manufacturing](../Acrylic%20Wall%20Manufacturing/README.md) directory.**
* **Tolerances:** The CAD models are designed with standard FDM tolerances. If your printer is not calibrated, you may need to adjust "Hole Horizontal Expansion" in your slicer or use a drill bit to clean up bolt holes (M3/M4).

---

## Versión en Español 🇪🇸

*Autor: Fernando Navarrete* ✍️

¡Bienvenido al **Repositorio de Diseño Digital** de la **Correa Transportadora Clasificadora REPOS V2**!

Este directorio contiene los archivos fuente de la estructura mecánica. Ya sea que desees modificar el diseño o simplemente exportar archivos para impresión 3D, aquí encontrarás todo lo necesario.

### 📂 1. Formatos de Archivo Disponibles
Proporcionamos los modelos en dos formatos estándar de la industria para asegurar la compatibilidad con tu software CAD preferido.

| Formato | Extensión | Descripción | Uso Recomendado |
| :--- | :---: | :--- | :--- |
| **Fusion 360** | `.f3d` | **Archivos Fuente Nativos.** Contiene el historial de diseño completo y la línea de tiempo paramétrica. | Ideal para **editar**, modificar dimensiones o hacer "remix" del proyecto usando Autodesk Fusion 360. |
| **STEP** | `.step` | **Formato de Intercambio Universal.** Modelo 3D estándar sin historial de diseño. | Ideal para importar en **SolidWorks, Inventor, Rhino, Onshape** o directamente en laminadores (slicers). |

### 🗂️ 2. Estructura de Directorios

> **📍 TIP DE NAVEGACIÓN:**
> Los archivos están organizados por formato. Elige la carpeta que coincida con tu flujo de trabajo: `../Fusion360` o `../STEP`.

Dentro de cada carpeta de formato, encontrarás la siguiente jerarquía organizada:

* 📄 **`Ensamble Correa Transportadora Miniatura`** (Archivo de Ensamblaje Principal):
    * Este es el **Ensamblaje Completo**. Contiene la máquina entera totalmente armada. Usa este archivo para entender cómo encajan las piezas, verificar holguras o ver el gemelo digital completo.
* 📁 **`/Electronic Parts`** (Sub-carpeta):
    * Contiene los modelos CAD del hardware electrónico y electromecánico activo (ej. *Motor Paso a Paso NEMA 17*, *EasyDriver A3967*, *Arduino*, *Servos SG90*, *PCB Personalizada*). Úsalos para referencias dimensionales y tolerancias de carcasas.
* 📁 **`/Mechanic Parts`** (Sub-carpeta):
    * Contiene los modelos CAD del hardware mecánico comercial estándar (ej. *Rodamientos 627zz*, *Imanes de Neodimio*, *Pernos M3/M4*). Esencial para comprobar el espacio libre de la tornillería.
* 📁 **`/Parts`** (Sub-carpeta):
    * Contiene los **Componentes Mecánicos Personalizados Individuales** diseñados específicamente para este proyecto (ej. *Tornillo Helicoidal*, *Polea Engranaje*, *Cámara Oscura*, *Cajas*).
    * **Usa estos archivos para Impresión 3D:** Abre los componentes individuales en esta carpeta para exportarlos como `.stl` o `.3mf` para tu software de laminado (slicer).

### ⚠️ Notas Importantes de Manufactura

* **Paredes Laterales de Acrílico:** Los archivos llamados `Soportes_Acrilico` se incluyen aquí solo como referencia de ensamblaje. **NO IMPRIMIR EN 3D ESTAS PIEZAS.** Están diseñadas para Corte Láser (Acrílico 4mm).
    * 👉 **Para los archivos de producción (`.dxf`, `.beam`) y parámetros láser, por favor revisa el directorio [Acrylic Wall Manufacturing](../Acrylic%20Wall%20Manufacturing/README.md).**
* **Tolerancias:** Los modelos CAD están diseñados con tolerancias estándar para FDM. Si tu impresora no está calibrada, podrías necesitar ajustar la "Expansión Horizontal de Agujeros" en tu slicer o usar una broca para limpiar los orificios de los pernos (M3/M4).

---
*Happy Making! / ¡Feliz Fabricación!* 🛠️

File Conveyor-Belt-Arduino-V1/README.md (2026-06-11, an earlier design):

 # Conveyor Belt Arduino DIY V1 (OUTDATED)🏗️🤖







*Author: Fernando Navarrete* ✍️

## English Version 🇺🇸

### 🌟 Project Overview

Welcome to the **Conveyor Belt Arduino DIY** repository! This project details the design, construction, and programming of an **Automatic Sorting Conveyor Belt**.

Powered by an **Arduino microcontroller**, this system utilizes a **TCS3200 Color Sensor** and high-precision **Servomotors** to classify objects based on their color (Red/Green). It is a multidisciplinary project integrating:

* **Mechanical Design** (3D Printing & Laser Cutting).

* **Electronics** (Wiring, Power Management, L298N Drivers).

* **Programming** (C++ logic for automation).

---

## Versión en Español 🇪🇸

### 🌟 Resumen del Proyecto

¡Bienvenido al repositorio **Conveyor Belt Arduino DIY**! Este proyecto detalla el diseño, construcción y programación de una **Cinta Transportadora Clasificadora Automática**.

Controlado por un microcontrolador **Arduino**, este sistema utiliza un **Sensor de Color TCS3200** y **Servomotores** de alta precisión para clasificar objetos según su color (Rojo/Verde). Es un proyecto multidisciplinario que integra:

* **Diseño Mecánico** (Impresión 3D y Corte Láser).

* **Electrónica** (Cableado, Gestión de energía, Drivers L298N).

* **Programación** (Lógica en C++ para automatización).

---

## 📚 Documentation & Modules / Documentación y Módulos

Explore the sub-directories below for detailed instructions on each aspect of the build.

*Explora los sub-directorios a continuación para instrucciones detalladas sobre cada aspecto de la construcción.*

| Module / Módulo | Description / Descripción |

| :--- | :--- |

| **📦 [Bill of Materials (BOM)](./Conveyor-Belt-Arduino-V1/BOM%20v1/README.md)** | **Purchase List & Printed Parts.** <br>Full list of hardware (Bolts, Bearings, Motors) and the catalog of STL parts required for 3D printing.<br>---<br>**Lista de Compra y Piezas Impresas.**<br>Listado completo de hardware (Pernos, Rodamientos, Motores) y catálogo de STLs para imprimir. |

| **📐 [CAD Design Files](./Conveyor-Belt-Arduino-V1/CAD%20v1/README.md)** | **Source Models (Fusion 360 & STEP).** <br>Download the digital twin of the machine. Includes assembly files and individual part files for modification.<br>---<br>**Modelos Fuente (Fusion 360 y STEP).**<br>Descarga el gemelo digital de la máquina. Incluye archivos de ensamblaje y piezas individuales para modificar. |

| **🔦 [Acrylic Manufacturing](./Conveyor-Belt-Arduino-V1/Acrylic%20Wall%20Manufacturing/README.md)** | **Laser Cutting Files.** <br>Production files (`.dxf`, `.beam`) for the transparent 4mm side walls, critical for the structure.<br>---<br>**Archivos de Corte Láser.**<br>Archivos de producción (`.dxf`, `.beam`) para las paredes laterales transparentes de 4mm, críticas para la estructura. |

| **⚡ [Electronics & Wiring](./Conveyor-Belt-Arduino-V1/Electronics%20v1/README.md)** | **Schematics & Diagrams.** <br>How to wire the L298N, TCS3200 Sensor, and Servos. Includes common ground and soldering tips.<br>---<br>**Esquemas y Diagramas.**<br>Cómo cablear el L298N, Sensor TCS3200 y Servos. Incluye consejos de soldadura y tierra común. |

| **💻 [Software & Logic](./Conveyor-Belt-Arduino-V1/Code%20v1/README.md)** | **Arduino Firmware.** <br>Source code (`.ino`) for the sorting logic and the calibration utility for the color sensor.<br>---<br>**Firmware de Arduino.**<br>Código fuente (`.ino`) para la lógica de clasificación y la utilidad de calibración del sensor de color. |

| **📸 [Multimedia Gallery](./Multimedia/README.md)** | **Renders & Visuals.** <br>High-quality renders of the assembly, internal views, and future photos of the prototype.<br>---<br>**Renders y Visuales.**<br>Renders de alta calidad del ensamblaje, vistas internas y futuras fotos del prototipo. |

---

## 🎓 Acknowledgments / Agradecimientos

This project was made possible thanks to the support and facilities provided by the **University of Chile**.

*Este proyecto fue posible gracias al apoyo y las instalaciones provistas por la **Universidad de Chile**.*

| Institution / Institución | Contribution / Contribución |

| :---: | :--- |

| LEMUR Logo | **LEMUR (Laboratorio de Ingeniería Mecatrónica y Robótica)**<br>For providing the workspace, 3D printers, and tools required for the belt assembly.<br>*(Por proveer el espacio, impresoras 3D y herramientas necesarias para el ensamblado de la correa).* |

| FabLab Logo | **FABLAB U. de Chile**<br>For their technical advisory and access to specialized machinery, specifically the Beambox Series Pro laser cutter.<br>*(Por su asesoría y el uso de máquinas especializadas, principalmente la cortadora láser Beambox Series Pro).* |

---

*Open Source Project - 2025*

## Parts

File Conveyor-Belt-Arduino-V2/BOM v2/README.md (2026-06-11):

# Conveyor Belt Arduino DIY - Bill of Materials 📦🤖

*Author: Fernando Navarrete* ✍️

## English Version 🇺🇸

Welcome to the **REPOS Sorting Conveyor Belt V2** project! 🎉

This innovative solution is designed to transform how objects are classified using advanced **color detection** and precise **electromechanical actuators**. Its **modular construction** ensures easy maintenance and adaptability for future expansions.

This document contains the complete **Bill of Materials (BOM)** required to build the physical structure for the Version 2. 🏗️

### 📋 1. Hardware & Electronics
These components are essential for the movement and control logic of the system.

| Component Name | Description / Specs | Qty | Notes |
| :--- | :--- | :---: | :--- |
| **Stepper Motor** | NEMA 17 Stepper Motor | 1 | Main drive unit for precise positioning |
| **Motor Driver** | EasyDriver A3967 Module | 1 | Microstepping driver for stepper motor |
| **Voltage Regulator** | LM2596 DC-DC Step-Down Buck Converter | 1 | Steps down battery voltage to stable 5V for logic/servos |
| **Capacitor** | 470µF Electrolytic Capacitor | 1 | Decoupling/Filter capacitor for voltage stability |
| **Custom PCB** | "Mechatronics Challenge 2" Custom Board | 1 | Centralized circuit board for clean routing |
| **Pin Headers** | Male & Female Pin Headers (2.54mm pitch) | Coll. | For modular connections and component mounting |
| **Color Sensor** | GY-31 / TCS3200 | 1 | 64 photodiodes sensor |
| **Servos** | SG90 Servomotors | 2 | Includes horns/arms |
| **Batteries** | Li-Ion 18650 (3.7V) | 3 | High voltage power source for NEMA 17 |
| **Battery Holder** | Holder for 3x18650 | 1 | |
| **Switch** | SPST Switch (2 pins, 20mm diam.) | 1 | Power control |
| **Bearings** | 627zz (7x22x7mm) | 4 | SKF standard radial |
| **Magnets** | Neodymium 12x4mm | 4 | For bearing covers |
| **Bolts M3x8** | ISO M3 Cylindrical Head | 40 | Main structure and driver fixation |
| **Bolts M4x8** | ISO M4 Cylindrical Head | 8 | Wall supports |
| **Microcontroller** | Arduino Uno/Nano | 1 | *Logic Unit (Required)* |

### 🖨️ 2. 3D Printed Parts

> **📂 CAD FILES LOCATION:**
> All 3D models listed below can be found in the **`../CAD v2`** directory.
> * **Supported Formats:** Fusion 360 (`.f3d`) and STEP (`.step`/`.stp`).
> * **Assembly Guide:** Please refer to the **[CAD v2 README](../CAD%20v2/README.md)** for detailed assembly views.

List of parts to be printed (STL). Recommended material: **PLA**, **PETG** or **TPU** where specified.
*Note: The filenames below correspond to the files located in `../CAD v2/Fusion360/Parts` or `../CAD v2/STEP/Parts`.*

> **⚖️ Weight Note:** The weights listed below were estimated using **Bambu Studio Slicer**. Values may vary slightly depending on your specific filament brand and infill settings.

| Part Name (Filename) | Description | Qty | Weight (g) |
| :--- | :--- | :---: | :---: |
| `Correa_V_Trapezoidal` | V-shaped thin conveyor belt (Printed in 2 parts, TPU Rec.) | 1 | |
| `Polea_Engranaje` | Power transmission gear pulley for the belt | 1 | |
| `Tornillo_Helicoidal_Nema` | Worm screw mounted on NEMA 17 to drive the gear pulley | 1 | |
| `Polea_Guia` | Toothless idler pulley for belt guidance | 1 | |
| `Ejes_7mm` | Printed 7mm shafts to connect pulleys with side bearings | 2 | |
| `Carcasa_Motor` | Custom enclosure and mount for NEMA 17 motor | 1 | |
| `Espaciadores_Estructurales_Sup` | Upper structural spacers to separate the belt from above | 2 | |
| `Espaciadores_Estructurales_Inf` | Lower structural spacers to separate the belt from below | 2 | |
| `Apoyos_Laterales_Dobles` | Connected side supports for increased structural stability | 2 | |
| `Espaciador_Central` | Central spacer to maintain the belt completely horizontal | 1 | |
| `Camara_Oscura` | Darkened chamber enclosure for housing the color sensor | 1 | |
| `Cortinas_Lamas` | Slats curtains for light isolation inside the chamber (TPU Rec.) | 2 | |
| `Rack_Cables` | Internal cable management rack and routing support | 1 | |
| `Carcasas_Servomotores` | Dedicated mounts/enclosures for the SG90 servos | 2 | |
| `Palas_Servomotores` | Pushing blades attached to servos for object sorting | 2 | |
| `Cajas_Receptoras_Simples` | Standard receiving boxes for object classification | 3 | |
| `Tapas_Rodamientos` | Bearing covers with slots for neodymium magnets (prevents axial sliding) | 4 | |

> **Note:** The *Soportes_Acrilico* connect the structure. While listed here, using **Laser Cutting** (3mm-5mm Acrylic) is recommended for visibility. Check `../Conveyor-Belt-Arduino-V1/Acrylic Wall Manufacturing` for details.

### 🛠️ 3. Tools & Consumibles
Don't forget these to ensure a smooth assembly!

* **Allen Keys / Screwdrivers:** For M3 and M4 bolts.
* **Soldering Iron & Solder:** For motor, driver, PCB components and switch connections.
* **Glue/Adhesive:**
    * Cyanoacrylate glue (for joining the TPU belt parts).
    * For fixing bearings (if loose).
    * For attaching magnets to covers.
* **Wires:** Jumper wires or layout wires for electronics.

---

## Versión en Español 🇪🇸

*Autor: Fernando Navarrete* ✍️

¡Bienvenido al proyecto **Correa Transportadora Clasificadora REPOS V2**! 🎉

Esta innovadora solución transforma la manera de clasificar objetos mediante una **avanzada detección de colores** y la integración precisa de **actuadores electromecánicos**. Su **construcción modular** facilita el mantenimiento y futuras ampliaciones.

Este documento contiene la **Lista de Materiales (BOM)** completa para construir la estructura física de la Versión 2. 🏗️

### 📋 1. Hardware y Electrónica
Estos componentes comerciales son necesarios para la motricidad y lógica del sistema.

| Nombre Componente | Descripción / Specs | Cant. | Notas |
| :--- | :--- | :---: | :--- |
| **Motor Paso a Paso** | Motor paso a paso NEMA 17 | 1 | Unidad de potencia para posicionamiento preciso |
| **Driver Motor** | Módulo EasyDriver A3967 | 1 | Controlador de micropasos para motor stepper |
| **Regulador de Voltaje** | Convertidor Buck DC-DC Step-Down LM2596 | 1 | Reduce el voltaje de baterías a 5V estables para lógica/servos |
| **Condensador** | Condensador Electrolítico de 470µF | 1 | Filtro de desacoplo para mitigar picos de corriente |
| **PCB Personalizada** | Placa de circuito "Desafío 2 Mecatrónica" | 1 | Placa centralizada para optimizar el ruteo eléctrico |
| **Pin Headers** | Conectores macho y hembra (Paso 2.54mm) | Kit | Para conexiones modulares y montaje de componentes |
| **Sensor Color** | GY-31 / TCS3200 | 1 | Sensor de 64 fotodiodos |
| **Servomotores** | Modelo SG90 | 2 | Con horquillas |
| **Baterías** | Ion de Litio 18650 (3.7V) | 3 | Fuente de alimentación de mayor voltaje para NEMA 17 |
| **Portapilas** | Soporte para 3x18650 | 1 | |
| **Switch** | Interruptor SPST (2 pines, 20mm) | 1 | Control encendido |
| **Rodamientos** | 627zz (7x22x7mm) | 4 | Norma SKF, radiales |
| **Imanes** | Neodimio 12x4mm | 4 | Para tapas |
| **Pernos M3x8** | Cabeza cilíndrica ISO M3 | 40 | Estructura principal y fijación de electrónica |
| **Pernos M4x8** | Cabeza cilíndrica ISO M4 | 8 | Apoyos laterales |
| **Microcontrolador** | Arduino Uno/Nano | 1 | *Unidad Lógica (Requerido)* |

### 🖨️ 2. Piezas Impresas en 3D

> **📂 UBICACIÓN ARCHIVOS CAD:**
> Todos los modelos 3D listados abajo se encuentran en el directorio **`../CAD v2`**.
> * **Formatos Compatibles:** Fusion 360 (`.f3d`) y STEP (`.step`/`.stp`).
> * **Guía de Ensamble:** Por favor revisa el **[README de CAD v2](../CAD%20v2/README.md)** para vistas detalladas.

Listado de archivos STL necesarios. Material recomendado: **PLA**, **PETG** o **TPU** según se especifique.
*Nota: Los nombres de archivo corresponden a los ubicados en `../CAD v2/Fusion360/Parts` o `../CAD v2/STEP/Parts`.*

> **⚖️ Nota sobre Pesos:** Los pesos listados a continuación fueron obtenidos a partir del laminador **Bambu Studio**. Los valores pueden variar según la marca de filamento y la configuración de relleno.

| Nombre Pieza (Archivo) | Descripción | Cant. | Peso (g) |
| :--- | :--- | :---: | :---: |
| `Correa_V_Trapezoidal` | Correa delgada en V (Impresa en 2 partes, Rec. TPU) | 1 | |
| `Polea_Engranaje` | Polea corona para la transmisión de potencia de la correa | 1 | |
| `Tornillo_Helicoidal_Nema` | Tornillo sin fin acoplado al NEMA 17 para mover la polea corona | 1 | |
| `Polea_Guia` | Polea loca lisa (sin dientes) para el guiado de la correa | 1 | |
| `Ejes_7mm` | Ejes de 7mm impresos para conectar poleas con rodamientos | 2 | |
| `Carcasa_Motor` | Soporte y carcasa de protección para el motor NEMA 17 | 1 | |
| `Espaciadores_Estructurales_Sup` | Separadores estructurales para la zona superior de la correa | 2 | |
| `Espaciadores_Estructurales_Inf` | Separadores estructurales para la zona inferior de la correa | 2 | |
| `Apoyos_Laterales_Dobles` | Soportes de paredes laterales unidos para mayor estabilidad | 2 | |
| `Espaciador_Central` | Soporte central para mantener la horizontalidad de la correa | 1 | |
| `Camara_Oscura` | Estructura de cámara cerrada para el sensor de color | 1 | |
| `Cortinas_Lamas` | Cortinas flexibles para aislar la luz en la cámara (Rec. TPU) | 2 | |
| `Rack_Cables` | Enrutador y soporte organizador para el cableado interno | 1 | |
| `Carcasas_Servomotores` | Carcasas de montaje para los servomotores SG90 | 2 | |
| `Palas_Servomotores` | Palas deflectoras de empuje para la clasificación de objetos | 2 | |
| `Cajas_Receptoras_Simples` | Depósitos contenedores para la separación de las piezas | 3 | |
| `Tapas_Rodamientos` | Tapas con alojamiento para imanes (evitan el juego axial del eje) | 4 | |

> **Nota:** Los *Soportes de Acrílico* estructuran la correa. Aunque están listados aquí, se recomienda usar **Corte Láser** (Acrílico 3mm-5mm). Revisa la carpeta `../Conveyor-Belt-Arduino-V1/Acrylic Wall Manufacturing` para los planos.

### 🛠️ 3. Herramientas y Consumibles
¡No olvides esto para asegurar un armado fluido!

* **Llaves Allen / Destornilladores:** Para pernos M3 y M4.
* **Cautín y Estaño:** Para soldar componentes en la PCB, motores e interruptor.
* **Pegamento/Adhesivo:**
    * Pegamento de cianoacrilato (para la unión de la correa de TPU).
    * Para fijar rodamientos (si entran muy holgados).
    * Para pegar imanes a las tapas.
* **Cables:** Cables tipo jumper o hilos de cobre para cableado interno de prototipos.

---
*Have fun building your **Conveyor Belt Arduino DIY V2**!* 🎊

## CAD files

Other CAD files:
Conveyor-Belt-Arduino-V2/CAD v2/STEP/Electronic Parts/PCB_Desafio_2.step
Conveyor-Belt-Arduino-V2/CAD v2/STEP/Mechanic Parts/Polea 50mm_w-10mm_s_3568N74_T Series Tim.step
Conveyor-Belt-Arduino-V2/CAD v2/STEP/Parts/Apoyos_Laterales_Dobles.step
Conveyor-Belt-Arduino-V2/CAD v2/STEP/Electronic Parts/Motor_Stepper_bipolar_NEMA_17_3.06V_1.7A_56N.cm_1.8_.step
Conveyor-Belt-Arduino-V2/CAD v2/STEP/Mechanic Parts/Timing Belt Trapezoidal.step
Conveyor-Belt-Arduino-V2/CAD v2/STEP/Parts/Pared_acrílico.step
Conveyor-Belt-Arduino-V2/CAD v2/STEP/Electronic Parts/SG90 - Micro Servo 9g - Tower Pro v1.step
Conveyor-Belt-Arduino-V2/CAD v2/STEP/Mechanic Parts/Radial Ball Bearing 627zz.step
Conveyor-Belt-Arduino-V2/CAD v2/STEP/Parts/Correa Transportadora 50mm_w-10mm_s.step
Conveyor-Belt-Arduino-V2/CAD v2/STEP/Electronic Parts/Battrey Case 16850x3.step
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

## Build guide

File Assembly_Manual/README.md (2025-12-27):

# Conveyor Belt Arduino DIY 🛠️🤖

*Author: Fernando Navarrete* ✍️

## English Version us

Welcome to **Conveyor Belt Arduino DIY**! 🎉  

This manual is designed to guide you through the **assembly of the physical parts** of a small Arduino-based sorting conveyor belt. 🏗️  
Some electronic components are included in the project, but **electrical connections are not detailed here**. Wiring and electronics will be covered in a separate section. ⚡  

### What you’ll find here:
- Step-by-step instructions for **assembling mechanical parts** 🧩  
- Guidelines for **fasteners and supports** 🔩  
- Tips for smooth operation and stability ⚙️  

### Project Overview:
This DIY project is perfect for learning basic **Arduino automation** and **mechanical assembly**. Once the physical structure is ready, you’ll be able to add and connect motors, sensors, and other electronics in the next phase.  

### Let’s Build! 💪
1. Unpack all parts and organize them by type.  
2. Follow the assembly steps in order: base → supports → belt → sorting mechanism.  
3. Use the recommended screws and nuts for each connection.  
4. Make sure all moving parts spin freely without obstruction.  

Have fun building your **Conveyor Belt Arduino DIY**! 🎊  

---

## Versión en Español 🇪🇸

*Autor: Fernando Navarrete* ✍️

¡Bienvenido a **Conveyor Belt Arduino DIY**! 🎉  

Este manual está diseñado para guiarte en el **armado de las partes físicas** de una pequeña correa transportadora clasificadora basada en Arduino. 🏗️  
Algunos componentes electrónicos ya están incluidos en el proyecto, pero **las conexiones eléctricas no se detallan aquí**. La sección de electrónica se cubrirá en una sección aparte. ⚡  

### Qué encontrarás aquí:
- Instrucciones paso a paso para **armar las piezas mecánicas** 🧩  
- Guías sobre **sujetadores y soportes** 🔩  
- Consejos para un funcionamiento estable y suave ⚙️  

### Resumen del proyecto:
Este proyecto DIY es perfecto para aprender **automatización con Arduino** y **armado mecánico**. Una vez que la estructura física esté lista, podrás añadir y conectar motores, sensores y otros componentes electrónicos en la siguiente fase.  

### ¡Manos a la obra! 💪
1. Desempaqueta todas las piezas y organízalas por tipo.  
2. Sigue los pasos de armado en orden: base → soportes → correa → mecanismo de clasificación.  
3. Usa los tornillos y tuercas recomendados en cada unión.  
4. Asegúrate de que todas las piezas móviles giren libremente sin obstáculos.  

¡Diviértete construyendo tu **Conveyor Belt Arduino DIY**! 🎊

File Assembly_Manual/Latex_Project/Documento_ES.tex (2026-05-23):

\section{Introducción}

\par ¡Gracias por elegir la Correa Transportadora Clasificadora de REPOS!
Diseñada por Fernando Navarrete, esta innovadora solución transforma la manera de clasificar objetos. Gracias a su avanzada detección de colores y la integración precisa de actuadores electromecánicos, podrás automatizar rutinas de clasificación de manera eficiente y confiable. \\

\par La Figura \ref{fig:1-Correa_armada} muestra el sistema completamente armado, listo para optimizar tus procesos de clasificación. Su diseño permite manejar distintos tamaños y tipos de objetos, ajustando la velocidad y la secuencia de los actuadores según tus necesidades. Además, su construcción modular facilita el mantenimiento y futuras ampliaciones del sistema, asegurando un rendimiento constante y adaptable a diferentes entornos. 

\begin{figure}[htbp]
    \centering
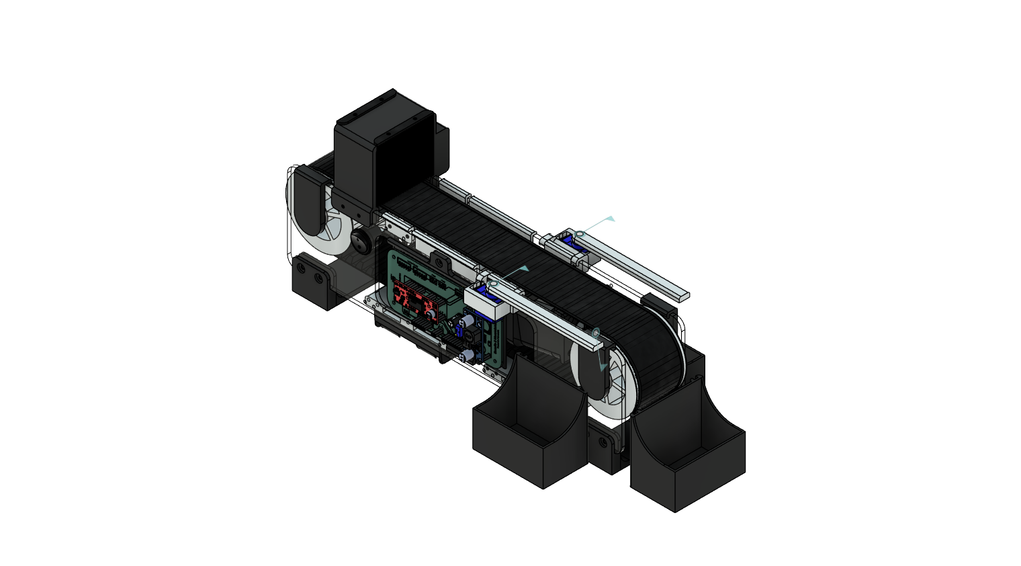
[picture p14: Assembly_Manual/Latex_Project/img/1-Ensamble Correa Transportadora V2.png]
    
    \caption{Correa Transportadora Clasificadora de Repos V2}
    \label{fig:1-Correa_armada}
\end{figure}

\par En las siguientes secciones, se detallarán los pasos a seguir para armar su Correa Transporadora Clasificadora de REPOS.

\clearpage
\section{Listado de materiales y de piezas}

\par Primero, se requieren los siguientes materiales para el armado de la correa transportadora, estos se detallan en la Tabla \ref{tab:2-materiales}.
\textbf{CANTIDAD DE PERNOS POR CALCULAR}
\begin{table}[H]
\centering
\caption{Listado de materiales por correa}
\begin{tabular}{|l|l|c|}
    \hline
    \textbf{Nombre} & \textbf{Descripción} & \textbf{Cantidad} \\
    \hline
    Pernos M3x8 & Pernos cabeza cilíndrica norma ISO M3 & - \\
    \hline
    Pernos M4x8 & Pernos cabeza cilíndrica norma ISO M4 & - \\
    \hline
    Pernos M3x4 & Pernos cabeza plana norma ISO M3 & - \\
    \hline
    Rodamientos 627zz & Rodamientos radiales norma SKF 7x22x7mm & 4 \\
    \hline
    Motor Paso a Paso & Motor Stepper Nema 17 40cm & 1 \\
    \hline
    EasyDriver A3967 & Controlador de motor Paso a Paso & 1 \\
    \hline
    Sensor GY-31/TCS3200 & Sensor a color de 64 fotodiodos & 1 \\
    \hline
    Servo SG90 & Servomotores modelo SG90 con horquillas & 2 \\
    \hline
    Batería 18650 & Batería Ion de Litio formato 18650 de 3.7V & 3 \\
    \hline
    Portapilas 3x18650 & Portapilas de Ion de Litio formato 18650 & 1 \\
    \hline
    Switch SPST 2 pines & Switch SPST de 2 pines y 20mm de diametro & 1 \\
    \hline
    Imanes de neodimio & Imanes de neodimio 12x4mm para tapas cubrerodamientos & 4 \\
    \hline
    PCB Desafío 2 & Placa de circuito impreso para el Desafío 2 & 1 \\
    \hline 
    Buck Step-Down LM2596 & Regulador de Voltaje DC a DC & 1 \\
    \hline
\end{tabular}
\label{tab:2-materiales}
\end{table}

\par Luego, el listado de piezas impresas necesario para ensamblar la correa transportadora, se muestra en la Tabla \ref{tab:2-piezas}.

\begin{table}[H]
    \centering
    \caption{Listado de piezas impresas en 3D para cada correa}
    \begin{tabular}{|l|l|c|}
        \hline
        \textbf{Nombre} & \textbf{Descripción} & \textbf{Cantidad} \\
        \hline
        Correa TPU dentada & Cadena dentada trapezoidal en V & 1 \\
        \hline
        Polea Engranaje & Polea dentada de transmisión modificada & 1 \\
        \hline
        Tornillo Helicoidal Nema & Tornillo Helicoidal 45° para el motor Nema 17 & 1 \\
        \hline
        Soporte Motor & Pieza de soporte del motor Nema & 1 \\
        \hline
        Polea Guía & Polea de guía sin dientes & 1 \\
        \hline
        Eje 7mm & Eje de 7mm de la unidad de soporte y transmisión & 2 \\
        \hline
        Soportes de acrílico & Soportes laterales de la correa de acrílico transparente & 2 \\
        \hline
        Separador estructural inferior & Piezas de apoyo para los soportes laterales de acrílico & 2 \\
        \hline
        Espaciador inferior & Pieza de soporte para portapilas & 2 \\
        \hline
        Espaciador superior & Espaciador y soporte para racks y soporte motor nema & 2 \\
        \hline
        Espaciador central & Pieza de soporte para correa y rack de cables & 1 \\
        \hline
        Soporte servomotor & Soportes para servos SG90 & 2 \\
        \hline
        Pala servomotores & Pala para empuje servos SG90 & 2 \\
        \hline
        Caja receptoras & Cajas receptoras de objetos clasificados & 3 \\
        \hline
        Rack de cables & Pieza de unión para ordenar cables en correa & 2 \\
        \hline
        Cámara Oscura & Cámara oscurecida para sensor a color & 1 \\
        \hline
        Cortinas de Lamas & Cortinas de lamas para cámara oscura & 2 \\
        \hline
        Soporte PCB & Pieza impresa para soportar PCB Desafío 2 & 1 \\
        \hline
        Tapas cubrerodamientos & Tapas para cubrir rodamientos y evitar que los ejes salgan & 4 \\
        \hline

    \end{tabular}
    \label{tab:2-piezas}
\end{table}

\clearpage
\section{Proceso de armado}

\textbf{POR ACTUALIZAR}

\par \textbf{Nota Feña:} Antes que nada, Vale, Emi, deben desarmar la versión anterior, remover los rodamientos pegados con silicona caliente y limpiar con alcohol isopropílico las paredes de acrílico. \\

\par Primero, se deben colocar los rodamientos en las paredes de acrílico y fijar usando pegamento de cianoacrilato (gotita). Es importante que los rodamientos sobresalgan hacia el interior de la correa. 

\begin{figure}[H]
    \centering
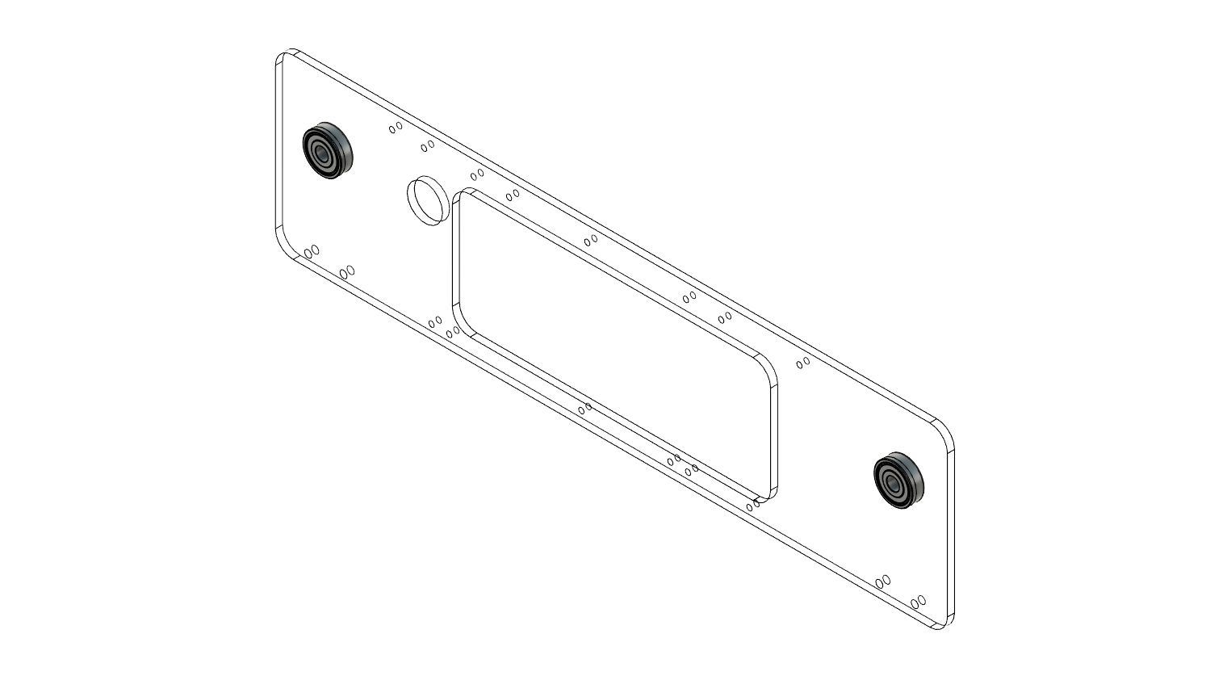
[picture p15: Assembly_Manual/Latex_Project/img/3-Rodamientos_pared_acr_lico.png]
    
    \caption{Pared de acrílico con rodamientos 627zz pegados.}
\end{figure}

\begin{figure}[H]
    \centering
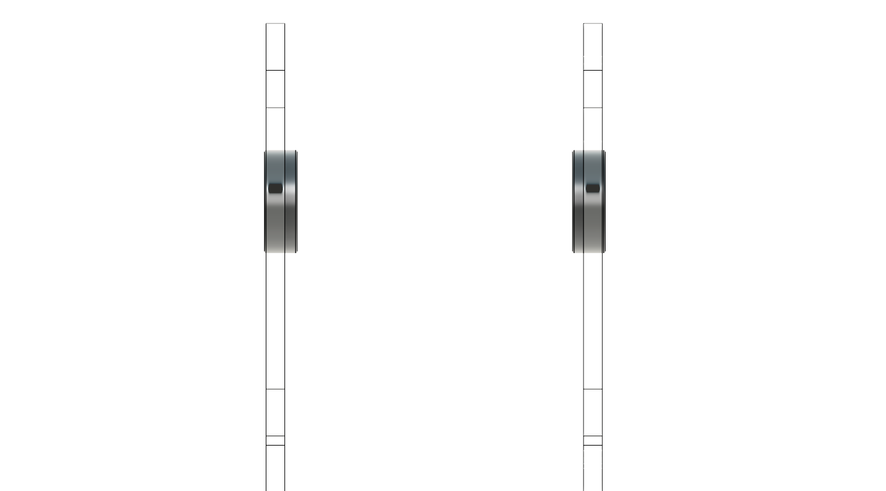
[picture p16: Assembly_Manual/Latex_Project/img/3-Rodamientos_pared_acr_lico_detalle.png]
    
    \caption{Pared de acrílico con rodamientos 627zz pegados. Vista de detalle.}
\end{figure}

\par Posteriormente, deben fijar la pared trasera primero a los soportes estructurales inferiores con pernos M4.

\begin{figure}[H]
    \centering
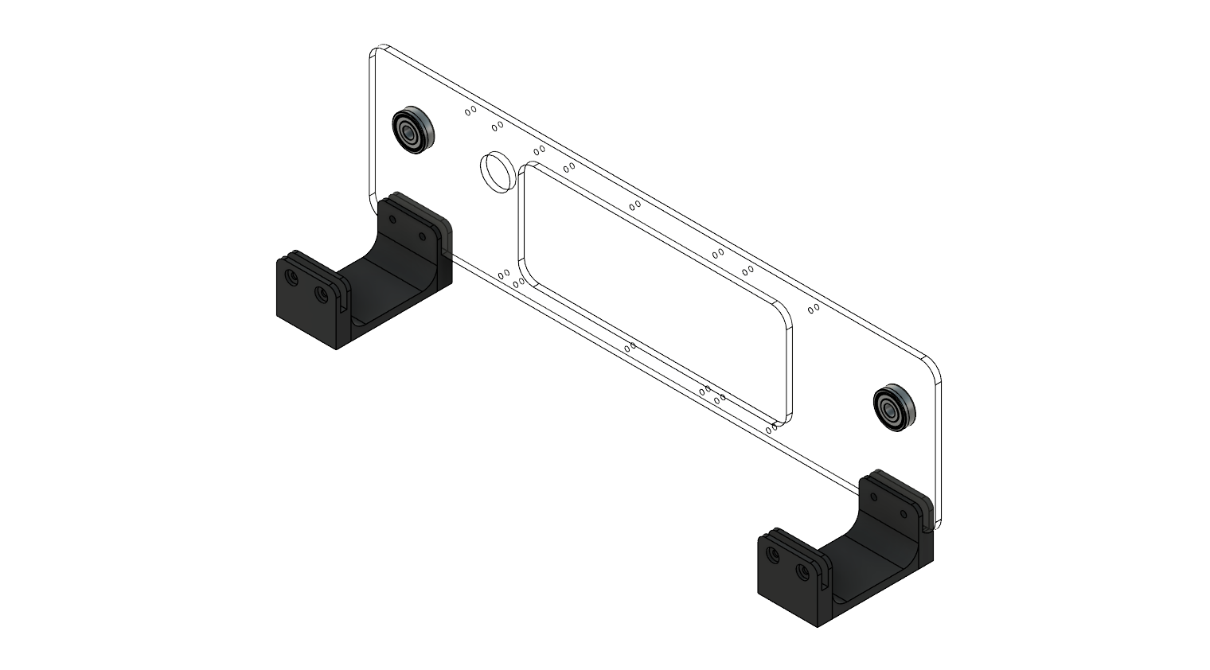
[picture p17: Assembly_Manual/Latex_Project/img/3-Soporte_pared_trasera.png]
    
    \caption{Soportes estructurales inferiores sujetando pared de acrílico trasera.}
\end{figure}

\par Ahora, deben preparar el ensamblaje del sistema de potencia y transmisión de la correa, que irá en la parte de descarga de la correa. Deben primero insertar al motor Nema el tornillo helicoidal y fijarlo con un perno M3 pequeño al eje del motor.

\begin{figure}[H]
    \centering
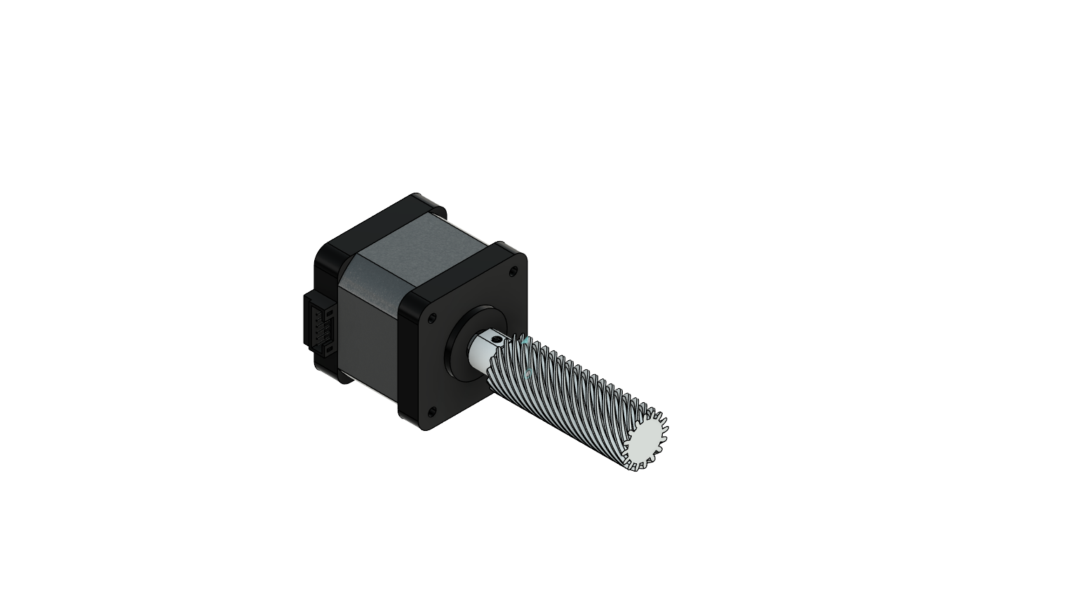
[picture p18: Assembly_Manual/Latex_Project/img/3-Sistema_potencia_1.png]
    
    \caption{Acople Tornillo helicoidal en el eje del motor Nema 17.}
\end{figure}

\par Posteriormente, deben colocar el motor sobre el soporte del motor nema con 4 pernos M3. Tener en consideración dejar los pines de alimentación orientados hacia afuera de la misma forma que se muestra en la imagen.

\begin{figure}[H]
    \centering
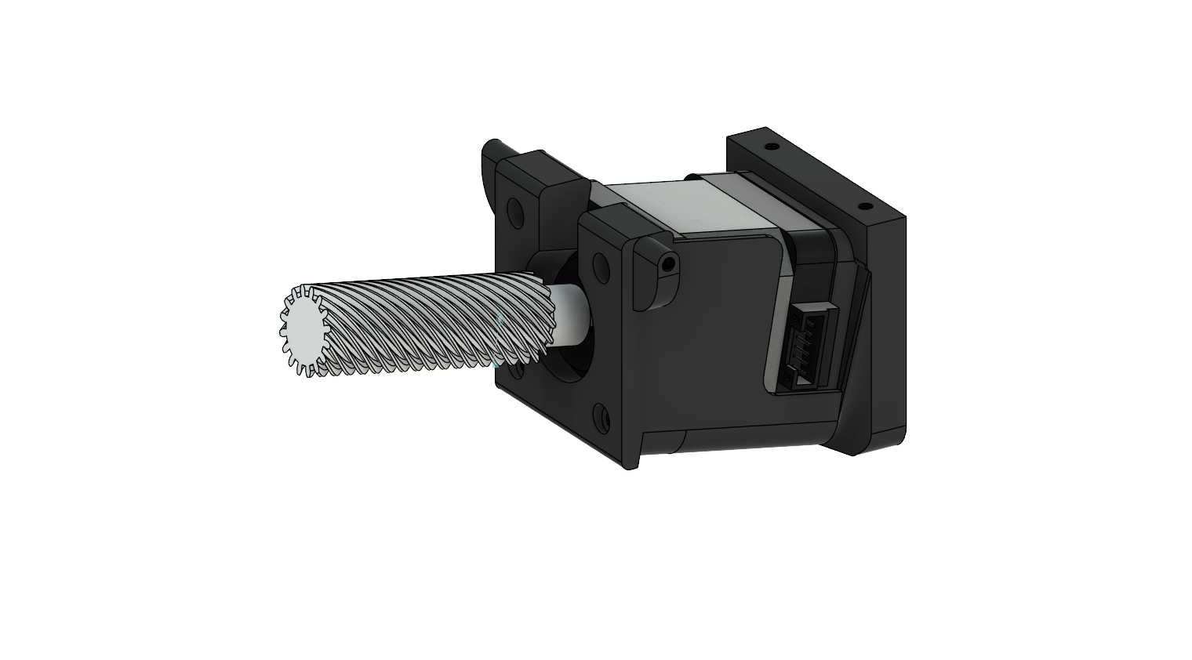
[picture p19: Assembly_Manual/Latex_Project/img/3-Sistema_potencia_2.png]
    
    \caption{Fijación motor Nema 17 al soporte de motor.}
\end{figure}

\par Luego, deben anclar un espaciador superior a las dos roscas del soporte de motor nema para completar el apoyo.

\begin{figure}[H]
    \centering
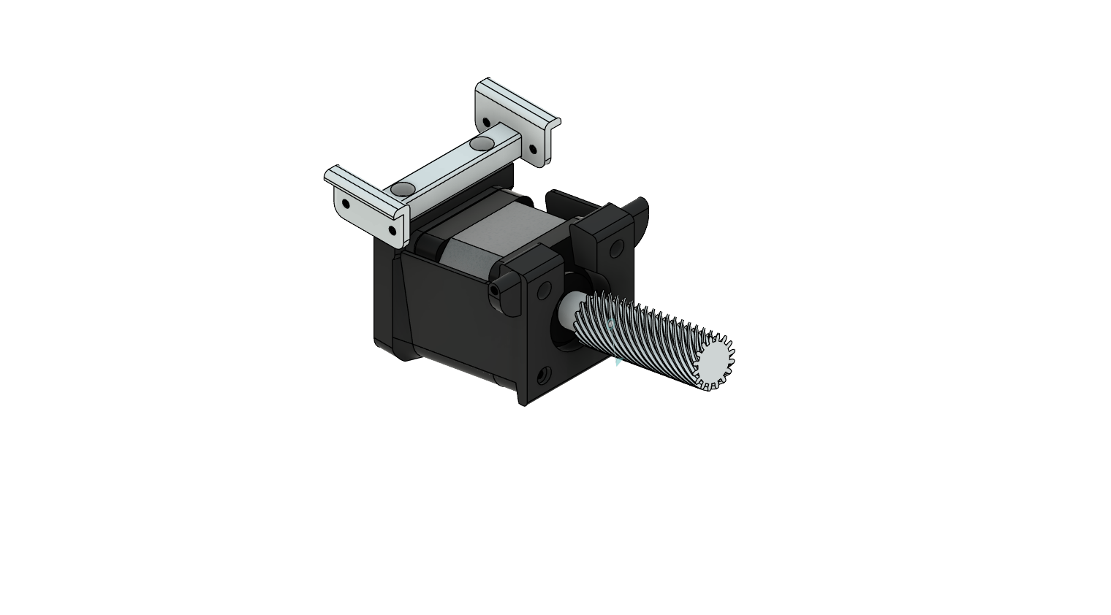
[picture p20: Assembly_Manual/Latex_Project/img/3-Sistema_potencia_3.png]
    
    \caption{Fijación soporte motor al espaciador superior.}
\end{figure}

\par Antes de montar el sistema de potencia, fijamos el eje de 7mm junto a la Polea engranaje en el rodamiento con la pared de acrílico.

\begin{figure}[H]
    \centering
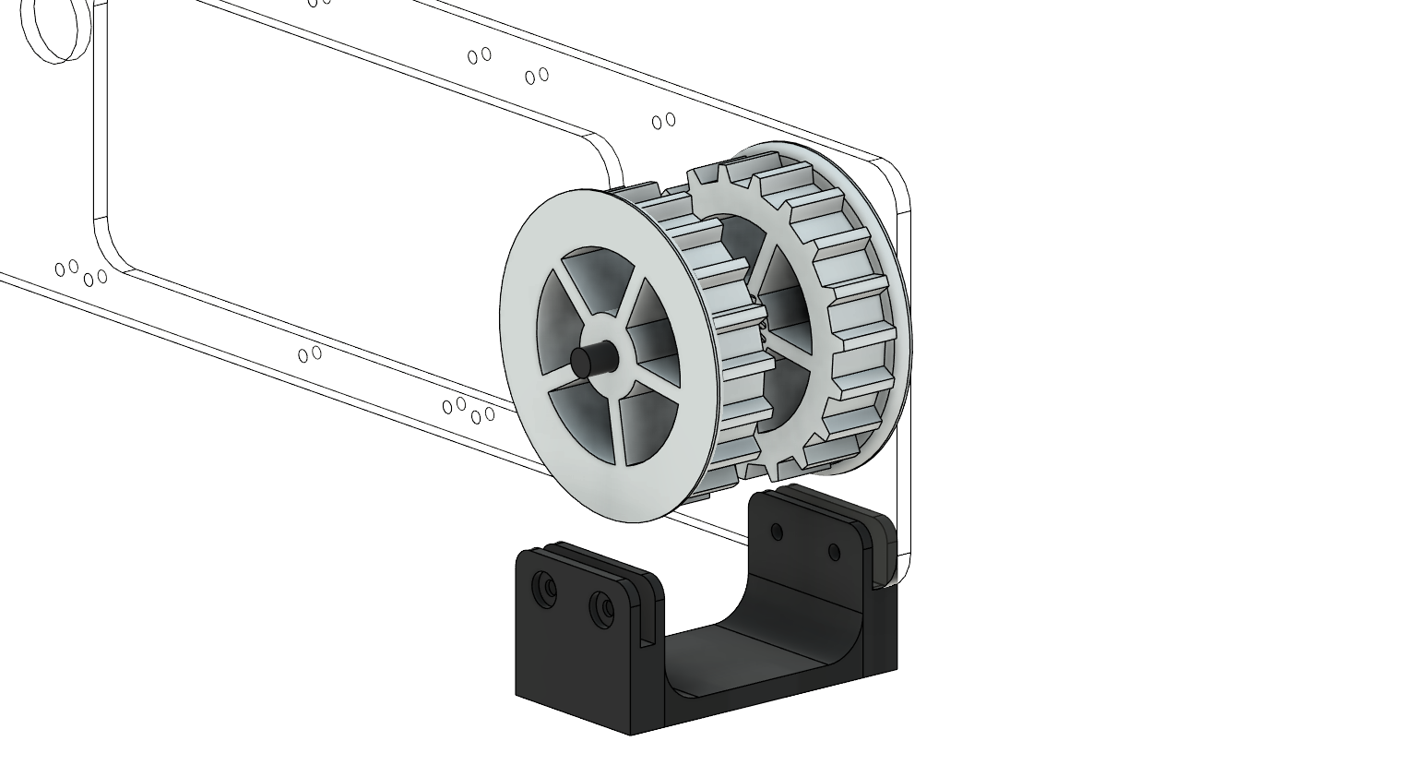
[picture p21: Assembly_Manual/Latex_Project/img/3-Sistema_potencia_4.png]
    
    \caption{Colocación eje y Polea engranaje antes de montar sistema de potencia.}
\end{figure}

\par Proceda a montar el sistema armado anteriormente, debe colocarse en dirección desde arriba, hasta abajo, apoyando el tornillo del motor nema sobre el tornillo de la Polea engranaje.

\begin{figure}[H]
    \centering
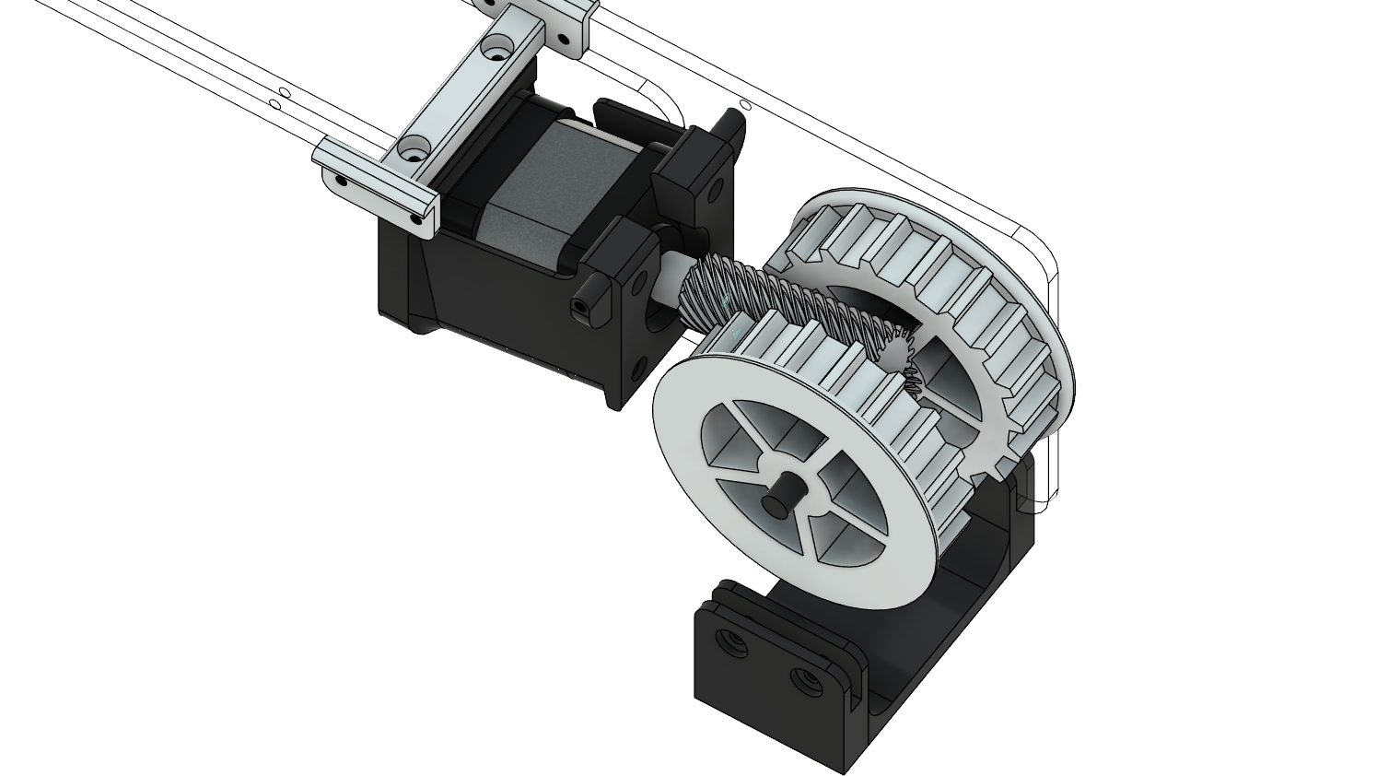
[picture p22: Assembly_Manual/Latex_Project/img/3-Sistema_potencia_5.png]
    
    \caption{Instalación sistema de potencia.}
\end{figure}

\par Tras este paso, debe añadir 3 pernos M3 a las fijaciones traseras del sistema instalado para evitar que se caiga momentáneamente. \\

\par Ahora, se procede a armar el sistema de manejo de cables y guía central de la correa. Para ello, debe unir las siguientes 3 piezas: Rack de cables, Espaciador central y Espaciador superior. Todo esto con pernos M3 cortos.

\begin{figure}[H]
    \centering
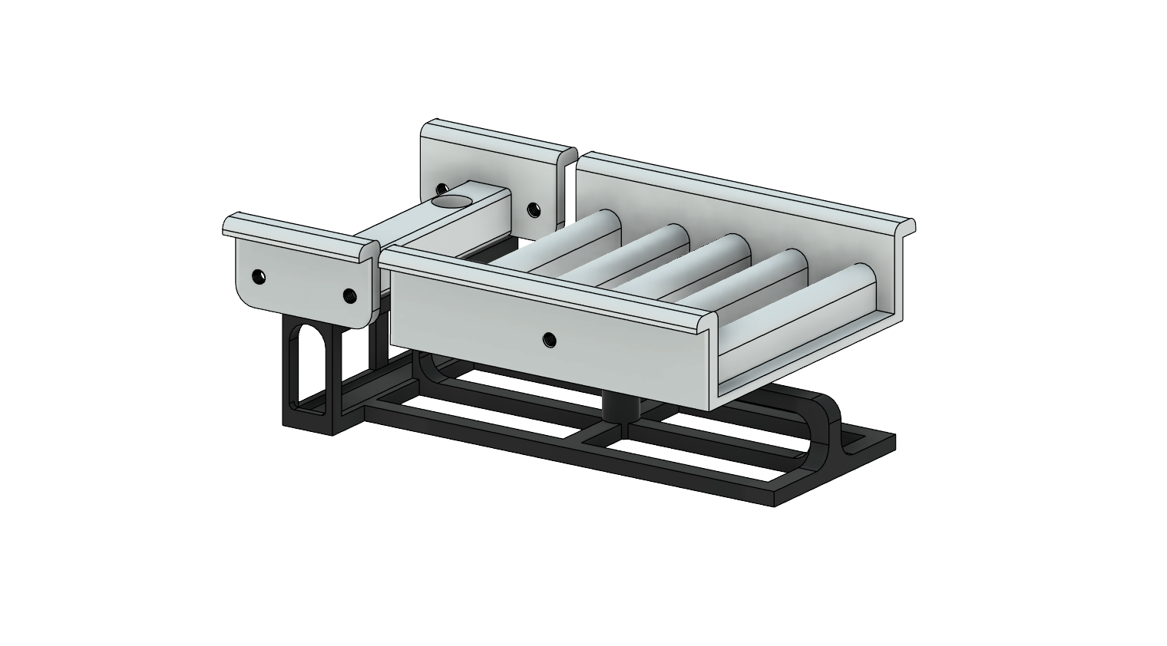
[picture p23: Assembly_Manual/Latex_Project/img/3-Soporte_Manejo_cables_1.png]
    
    \caption{Armado soporte de manejo de cables.}
\end{figure}

\par Proceda a instalarlo sobre la pared de acrílico trasera y fijarlo con pernos M3.

\begin{figure}[H]
    \centering
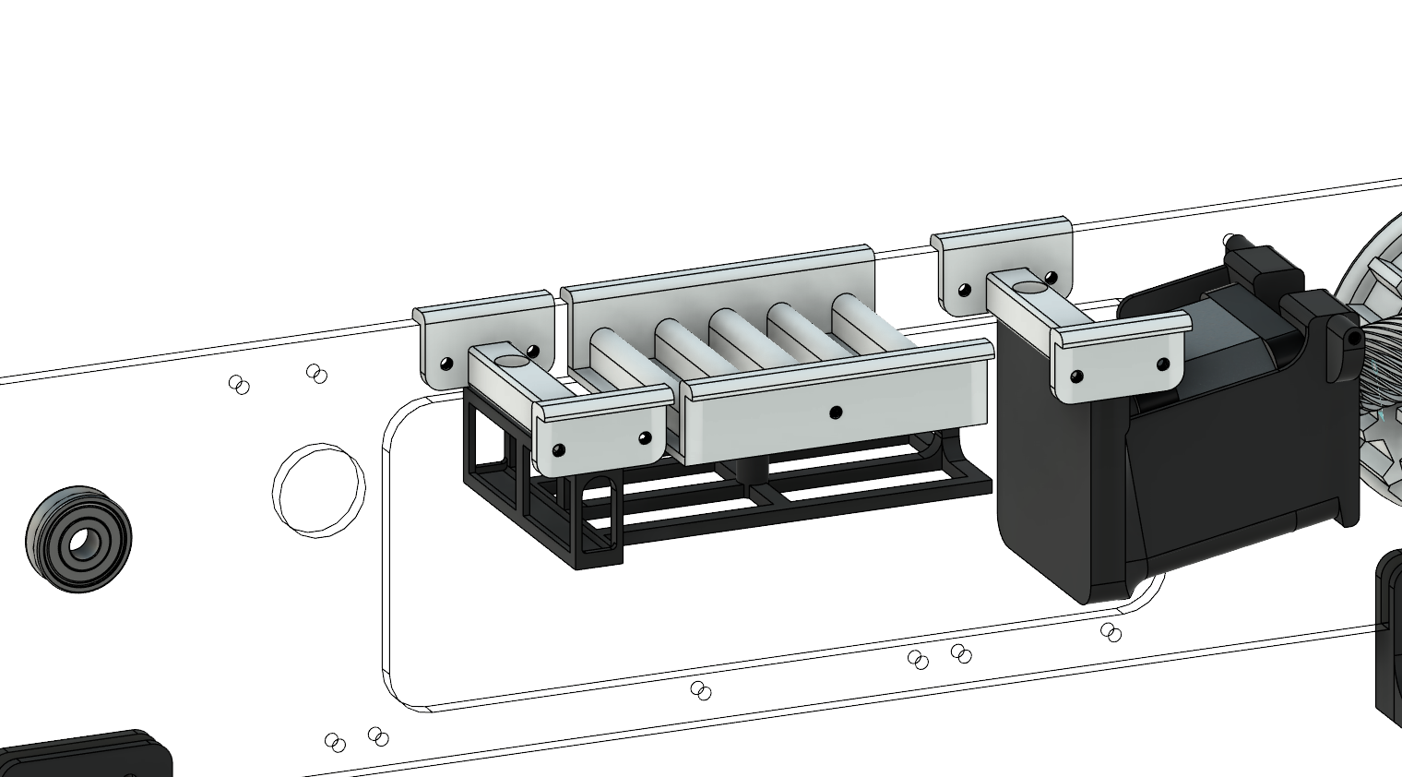
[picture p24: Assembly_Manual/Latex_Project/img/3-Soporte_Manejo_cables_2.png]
    
    \caption{Instalación soporte de manejo de cables.}
\end{figure}

\par Por otro lado, debe fijar un espaciador inferior junto al portapilas 3x18650 con pernos avellanados o de cabeza plana.

\begin{figure}[H]
    \centering
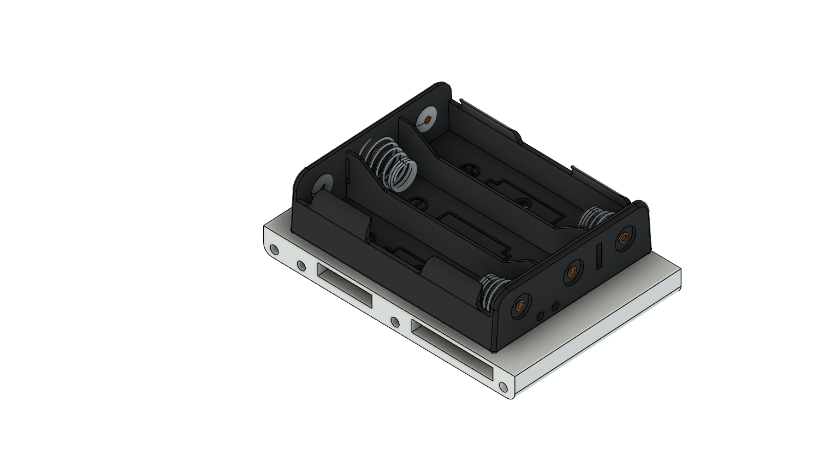
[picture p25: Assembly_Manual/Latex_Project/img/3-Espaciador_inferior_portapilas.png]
    
    \caption{Fijación portapilas a espaciador inferior.}
\end{figure}

\par Luego, lo atornilla con pernos M3 por el otro lado de la pared acrílica trasera (mínimo 2). Debe cuidar que la orientación de los cables sea hacia el lado izquierdo de la correa (en contra del sistema de potencia).

\begin{figure}[H]
    \centering
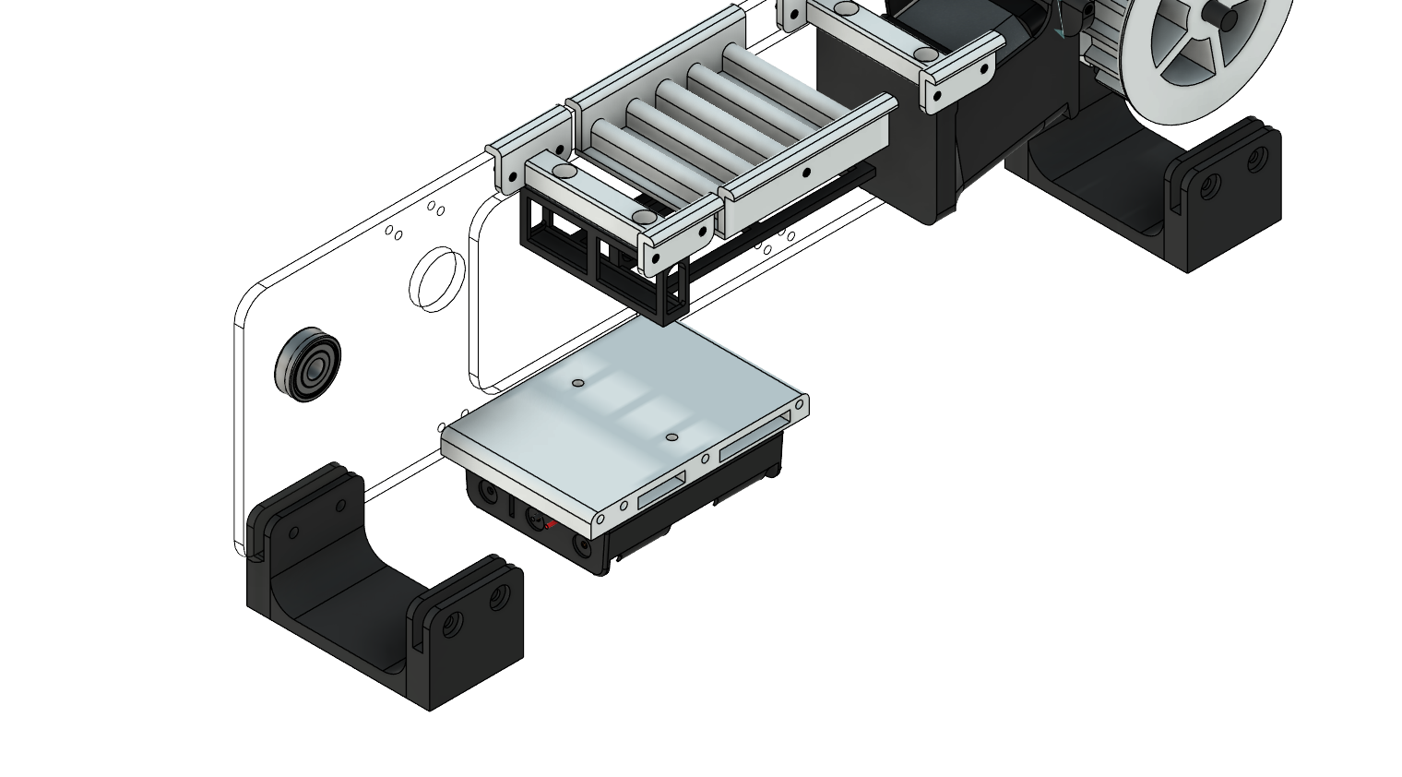
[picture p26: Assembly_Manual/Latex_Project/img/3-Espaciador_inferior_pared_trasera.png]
    
    \caption{Instalación espaciador inferior en pared acrílica trasera.}
\end{figure}

\par Nota: Deben colocar el otro espaciador inferior para brindar más soporte. 

\par Como paso previo a la instalación de la correa, se recomienda acomodarla con la Polea guía.

\begin{figure}[H]
    \centering
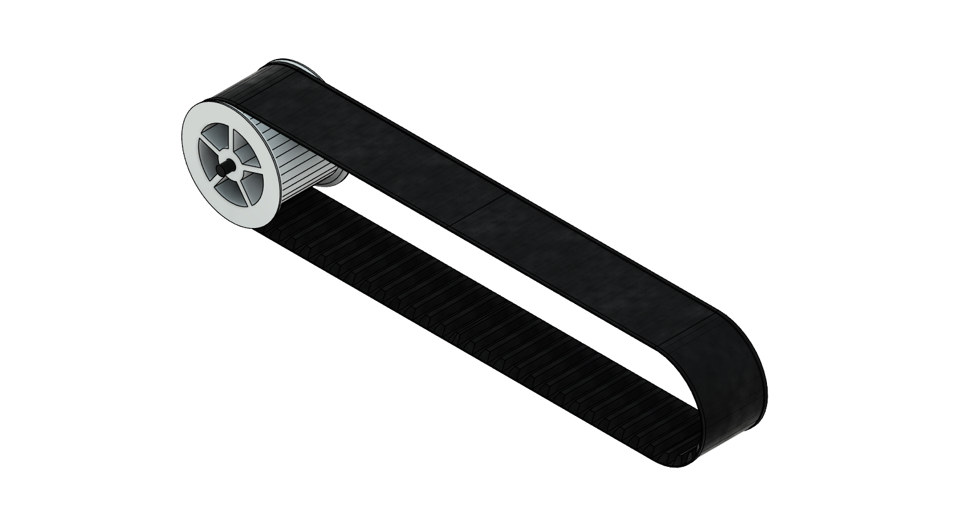
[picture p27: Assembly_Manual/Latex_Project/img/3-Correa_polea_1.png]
    
    \caption{Polea guía y correa transportadora.}
\end{figure}

\par De esta forma, debe insertarse el eje de la Polea guía en el rodamiento izquierdo y colocar cuidadosamente la correa hasta que quede montada y alineada con la Polea engranaje. 

\begin{figure}[H]
    \centering
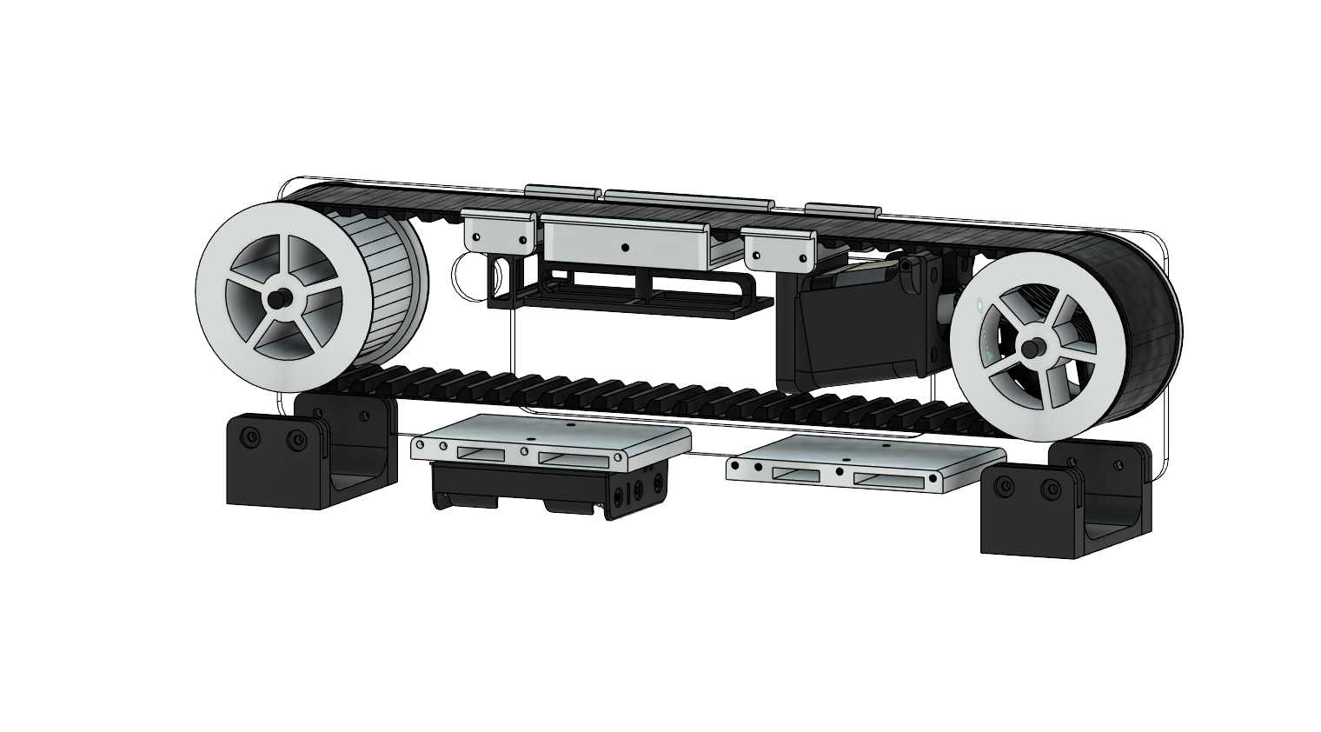
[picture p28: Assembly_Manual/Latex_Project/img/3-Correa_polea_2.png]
    
    \caption{Polea guía y correa transportadora.}
\end{figure}

\par Tras este paso, procedemos a colocar la otra pared de acrílico con rodamientos. Nótese que puede colocarse de forma horizontal y cuidando de luego colocar los ejes sobre los rodamientos (puede que deba doblar un poco la pared de acrílico, tenga cuidado). 

\begin{figure}[H]
    \centering
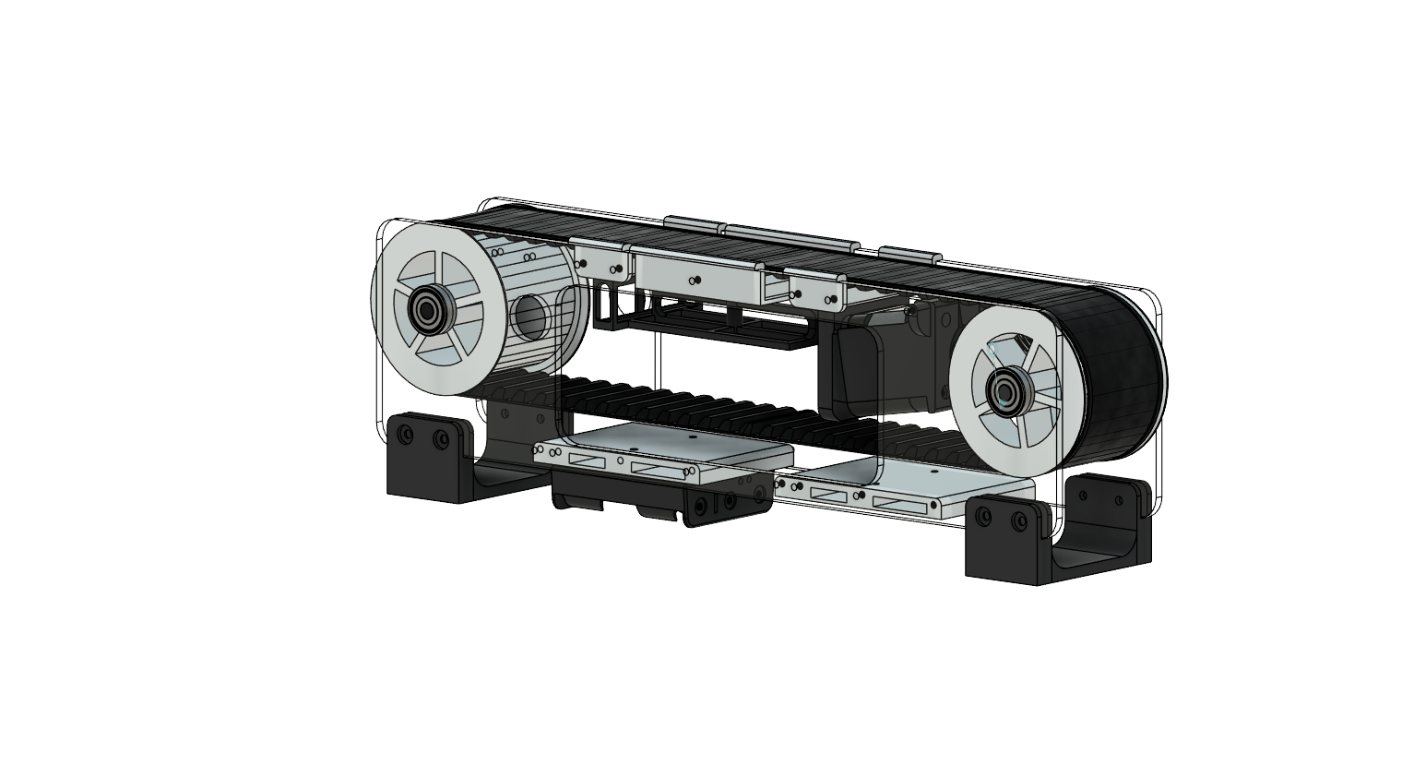
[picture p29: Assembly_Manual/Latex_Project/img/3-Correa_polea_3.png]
    
    \caption{Sistema de correa armado.}
\end{figure}

\par Recuerde fijar los soportes con pernos M3 y M4 por la parte frontal, así la correa quedará correctamente alineada y fija. \textbf{Solo omitir el perno frontal del Espaciador central}. \\

\par Ahora, para evitar desplazamientos de ambos ejes, se usarán tapas con imanes de neodimio. Primero debe conseguir los imanes y pegarlos en las tapas.

\begin{figure}[H]
    \centering
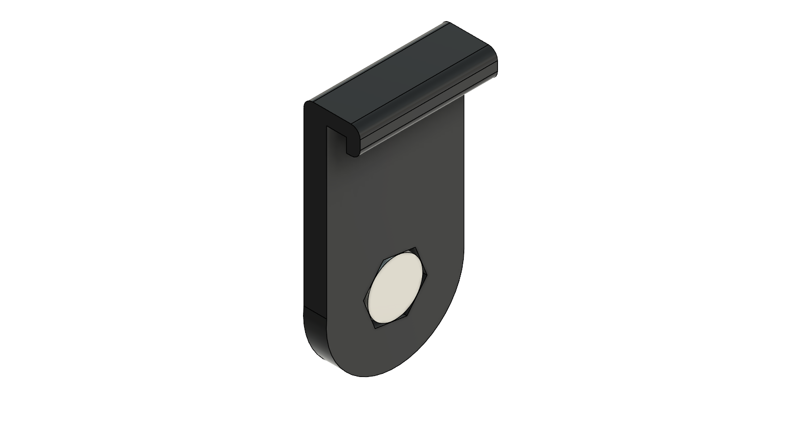
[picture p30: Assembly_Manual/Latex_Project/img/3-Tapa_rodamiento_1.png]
    
    \caption{Tapa de rodamiento con iman.}
\end{figure}

\par Debe preparar 4 por correa y luego insertarlos de forma simple en las paredes y gracias al magnetismo, se pegarán a los rodamientos. \textbf{Advertencia: debe colocarlos suavemente, pueden romperse al impactar.}

\begin{figure}[H]
    \centering
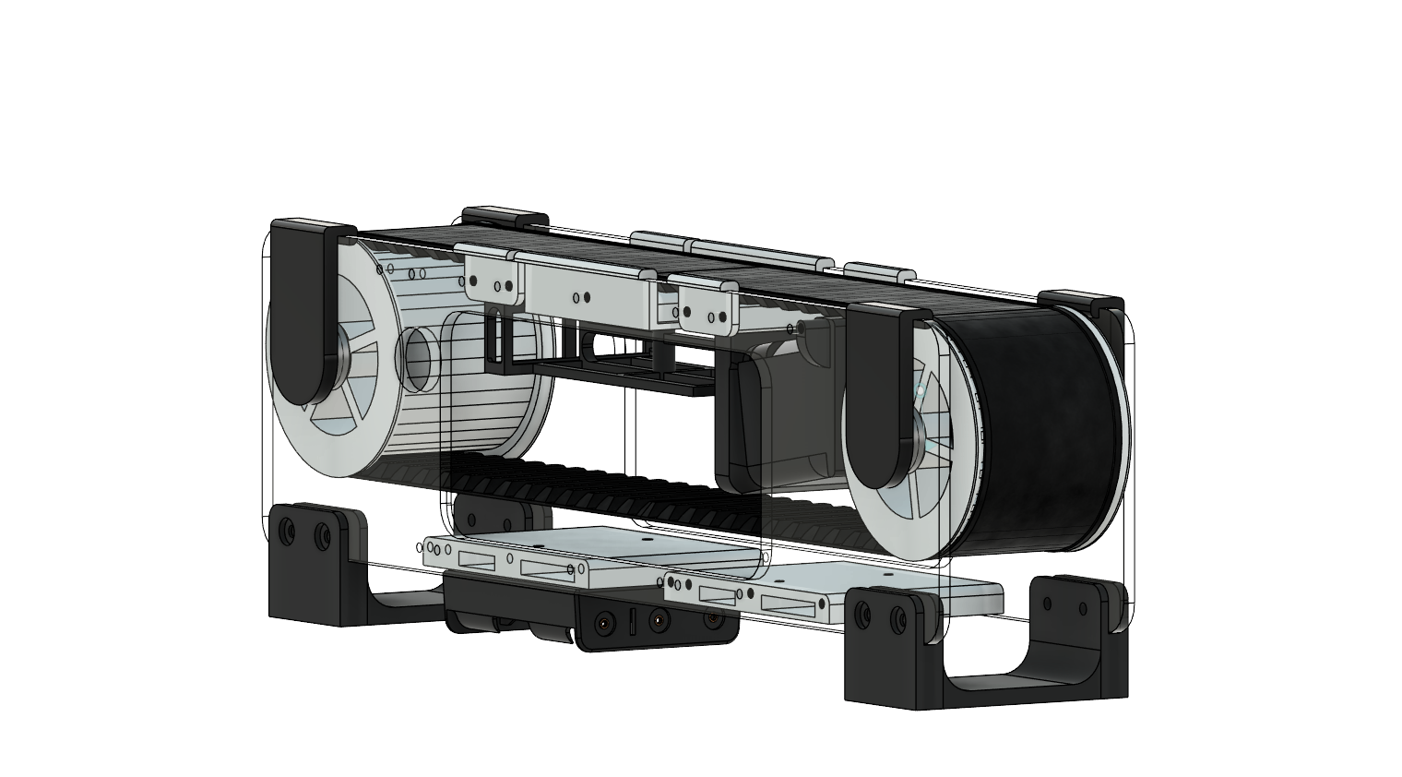
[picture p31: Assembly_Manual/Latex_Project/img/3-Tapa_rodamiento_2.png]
    
    \caption{Tapa de rodamiento colocadas en la correa.}
\end{figure}

\par Tras este paso, queda colocar los accesorios electrónicos y de clasificación de la correa. Primero, se debe preparar la Cámara oscura junto al sensor de color. Sujételo con pernos por fuera.

\begin{figure}[H]
    \centering
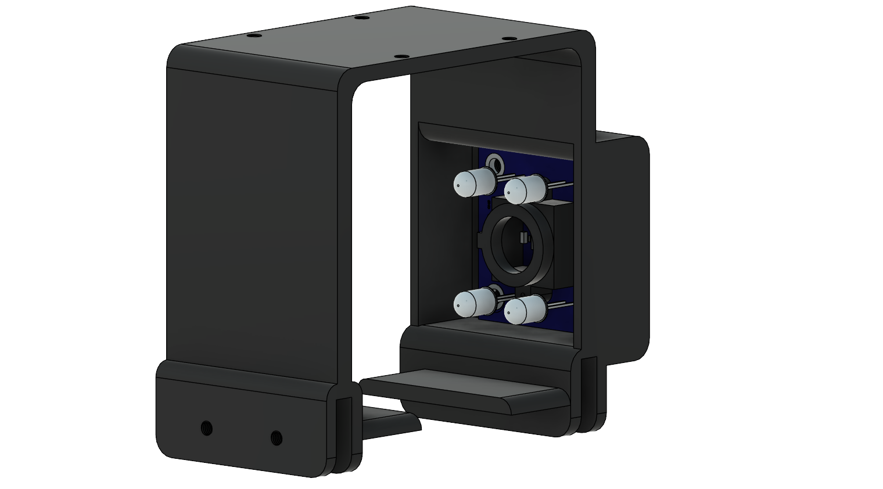
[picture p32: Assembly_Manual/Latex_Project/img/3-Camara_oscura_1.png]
    
    \caption{Cámara Oscura con sensor a color adherido.}
\end{figure}

\par Luego, debe colocar las cortinas de lamas con 2 pernos c/u sobre la cámara oscura para restringir la luz externa.

\begin{figure}[H]
    \centering
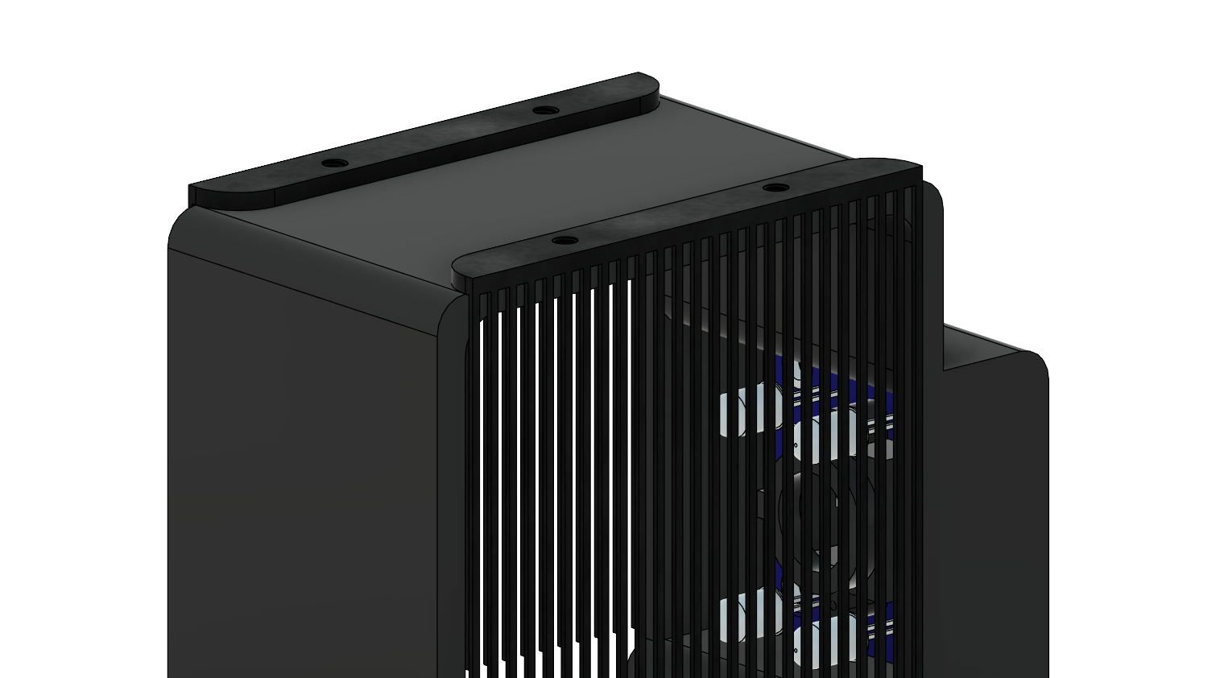
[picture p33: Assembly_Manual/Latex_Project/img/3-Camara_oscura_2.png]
    
    \caption{Cámara Oscura ensamblada.}
\end{figure}

\par Para ensamblar la Cámara Oscura, debe estirar levemente la correa y ponerla por dentro de la cámara a través de la ranura central inferior (esto sirve para mantener la correa nivelada). Luego debe fijarla con 4 pernos M3. \textbf{Debe cuidar que el lado del sensor esté mirando hacia atrás.}

\begin{figure}[H]
    \centering
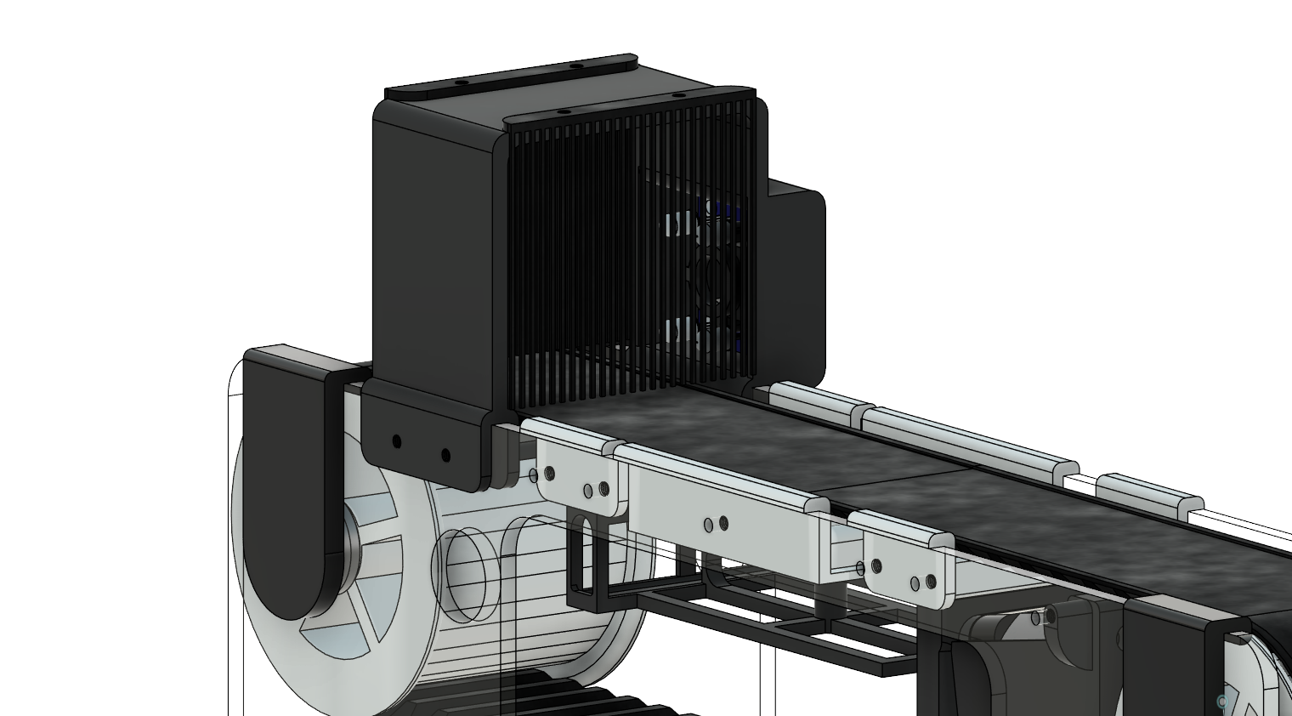
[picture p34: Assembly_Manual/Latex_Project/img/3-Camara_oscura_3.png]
    
    \caption{Cámara Oscura ensamblada en la correa.}
\end{figure}

\par Continuando el armado, el servomotor es simple de armar: se debe colocar en el soporte de servomotor y luego insertar la pala sobre el eje del servo. 

\begin{figure}[H]
    \centering
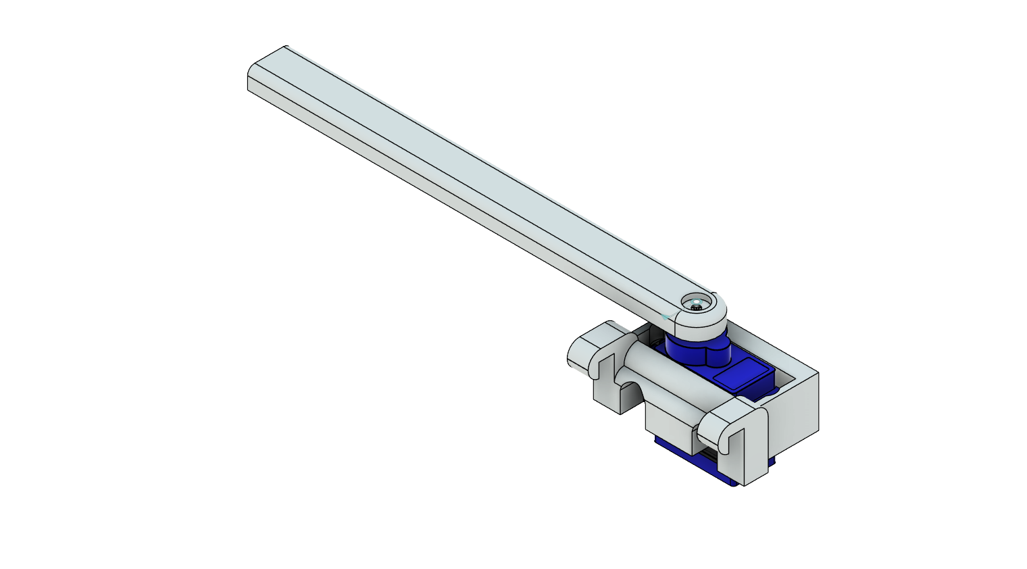
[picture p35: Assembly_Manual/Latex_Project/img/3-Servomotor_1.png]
    
    \caption{Soporte servomotor y pala ensamblados.}
\end{figure}

\par Para cuestiones de ensamble, observe que \textbf{ambos servomotores deben estar orientados a la derecha de la correa}, por lo que deberá ensamblar ambos servomotores con orientación diferente. Para este ensamble, \textbf{no se requieren pernos}, deben ir colocados directamente sobre los soportes superiores.

\begin{figure}[H]
    \centering
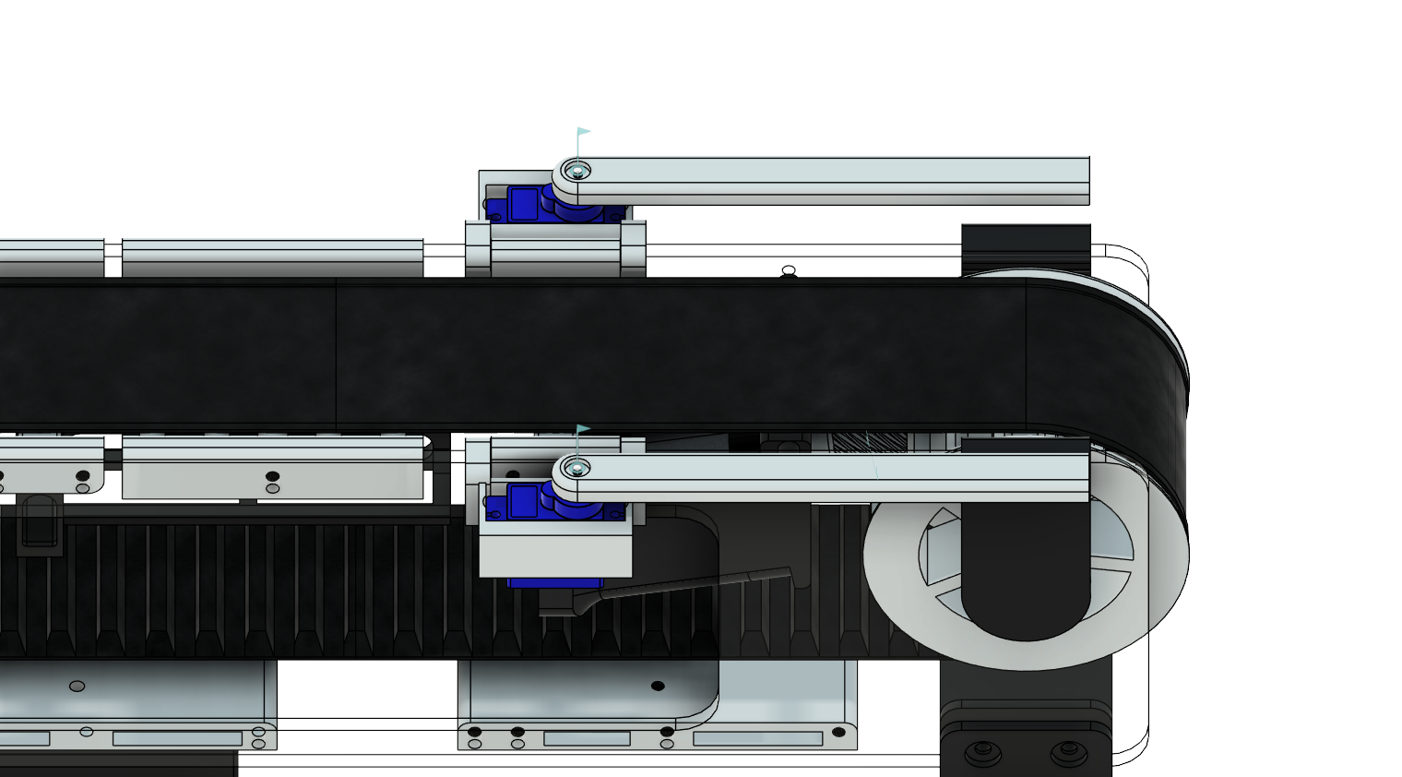
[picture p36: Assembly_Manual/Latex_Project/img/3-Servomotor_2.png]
    
    \caption{Soporte servomotor y pala ensamblados en la correa.}
\end{figure}

\par Posteriormente, debe ensamblar la PCB del Desafío 2 sobre el Soporte PCB para anclarlo a la correa. \textbf{Previamente deben estar todos los componentes y headers soldados.}

\begin{figure}[H]
    \centering
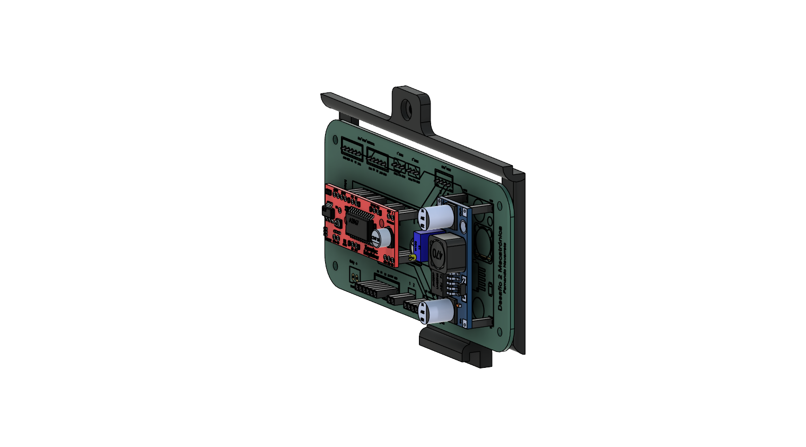
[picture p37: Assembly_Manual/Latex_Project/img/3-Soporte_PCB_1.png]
    
    \caption{Soporte PCB armado.}
\end{figure}

\par Luego, para ensamblarlo en la correa: fijar primero la pestaña inferior, luego girar y apoyar la rosca superior sobre el perno del espaciador central.

\begin{figure}[H]
    \centering
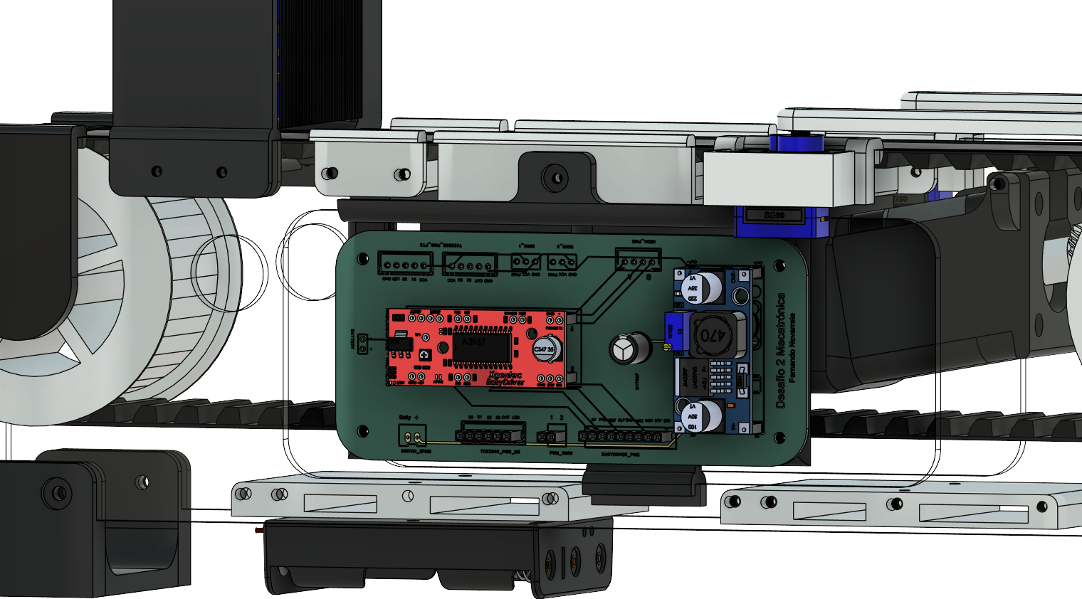
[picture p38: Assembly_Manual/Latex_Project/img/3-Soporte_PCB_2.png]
    
    \caption{Soporte PCB ensamblado.}
\end{figure}

\par Finalmente, se deben gestionar las conexiones eléctricas y colocar el Switch de 2 pines y las cajas receptoras en las posiciones objetivos mostradas en la última imagen.

\begin{figure}[H]
    \centering
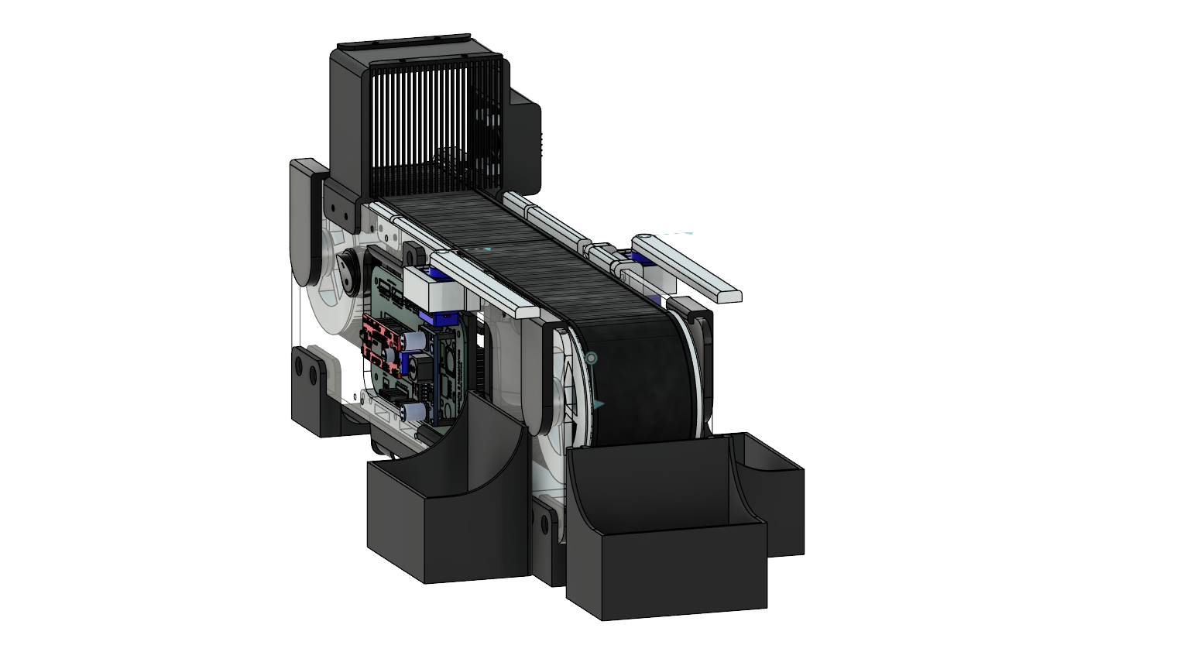
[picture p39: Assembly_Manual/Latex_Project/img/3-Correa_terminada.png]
    
    \caption{Correa Transportadora ensamblada.}
\end{figure}

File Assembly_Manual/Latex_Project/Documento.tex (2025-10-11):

\section{Introduction}

\par Thank you for choosing the REPOS Sorting Conveyor Belt!
Designed by Fernando Navarrete, this innovative solution transforms the way objects are sorted. With its advanced color detection system and precise integration of electromechanical actuators, you can automate sorting routines efficiently and reliably. \\

\par Figure \ref{fig:1-Correa_armada} shows the fully assembled system, ready to optimize your sorting processes. Its design allows handling different sizes and types of objects by adjusting the speed and sequence of the actuators according to your specific needs. Additionally, its modular construction facilitates maintenance and future expansions, ensuring consistent performance and adaptability to various environments. 

\begin{figure}[htbp]
    \centering
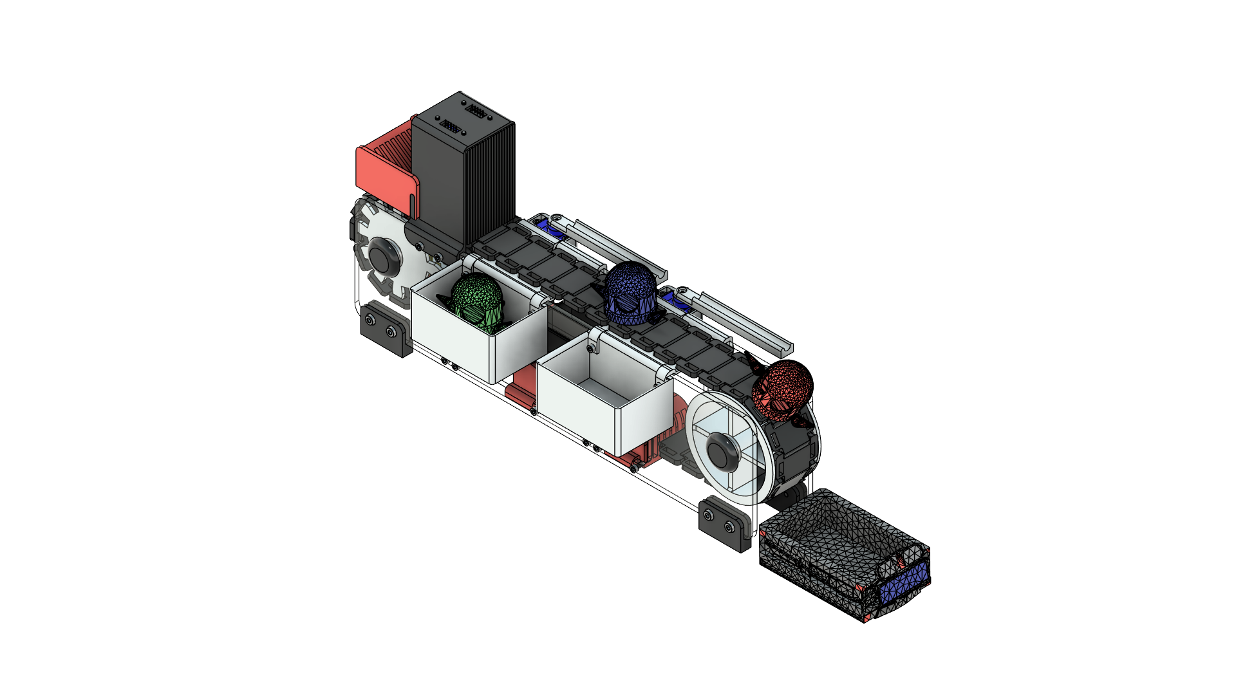
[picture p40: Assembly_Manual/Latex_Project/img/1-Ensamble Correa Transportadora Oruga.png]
    
    \caption{REPOS Sorting Conveyor Belt}
    \label{fig:1-Correa_armada}
\end{figure}

\par In the following sections, the steps required to assemble your REPOS Sorting Conveyor Belt will be detailed.

\clearpage
\section{Materials and Parts List}

\par First, the following materials are required to assemble the conveyor belt, as detailed in Table \ref{tab:2-materials}.

\begin{table}[H]
\centering
\caption{Materials list per conveyor belt}
\begin{tabular}{|l|l|c|}
    \hline
    \textbf{Name} & \textbf{Description} & \textbf{Quantity} \\
    \hline
    M3x8 Bolts & ISO M3 cylindrical head bolts & 40 \\
    \hline
    M4x8 Bolts & ISO M4 cylindrical head bolts & 8 \\
    \hline
    M3x4 Bolts & ISO M3 flat head bolts & 2 \\
    \hline
    627zz Bearings & SKF radial bearings 7x22x7mm & 4 \\
    \hline
    DC Motor & Yellow 6V DC motor with gearbox & 1 \\
    \hline
    L298N Driver & Motor driver L298N & 1 \\
    \hline
    GY-31/TCS3200 Sensor & 64-photodiode color sensor & 1 \\
    \hline
    SG90 Servo & SG90 servomotors with horns & 2 \\
    \hline
    18650 Battery & 3.7V lithium-ion 18650 battery & 2 \\
    \hline
    2x18650 Battery Holder & 18650 lithium-ion battery holder & 1 \\
    \hline
    SPST 2-pin Switch & 20mm diameter SPST switch & 1 \\
    \hline
    Neodymium Magnets & 12x4mm neodymium magnets for bearing covers & 4 \\
    \hline
\end{tabular}
\label{tab:2-materials}
\end{table}

\par Next, the list of 3D-printed parts required to assemble the conveyor belt is shown in Table \ref{tab:2-piezas}.

\begin{table}[H]
    \centering
    \caption{3D-printed parts list for each conveyor belt}
    \begin{tabular}{|l|l|c|}
        \hline
        \textbf{Name} & \textbf{Description} & \textbf{Quantity} \\
        \hline
        Track Chain & 43-link track chain & 1 \\
        \hline
        Front Motor Gear & Gear of the left power unit & 1 \\
        \hline
        Rear Motor Gear & Gear of the right power unit & 1 \\
        \hline
        Motor Mount & DC motor support piece & 1 \\
        \hline
        Cylinder & Support unit cylinder & 1 \\
        \hline
        7mm Shaft & 7mm shaft for the support unit & 1 \\
        \hline
        Acrylic Supports & Transparent acrylic side supports & 2 \\
        \hline
        Side Wall Supports & Support pieces for acrylic side supports & 4 \\
        \hline
        Lower Support & Component support pieces & 2 \\
        \hline
        Component Plate & Plate for L298N driver and batteries & 1 \\
        \hline
        Servo Mount & Mounts for SG90 servos & 2 \\
        \hline
        Servo Blades & Push blades for SG90 servos & 2 \\
        \hline
        Side Receiving Box & Boxes for sorted objects & 2 \\
        \hline
        Top Support & Piece connecting box and servos to keep belt level & 2 \\
        \hline
        Dark Chamber & Darkened chamber for color sensor & 1 \\
        \hline
        Slat Curtains & Curtains for dark chamber & 2 \\
        \hline
        Loading Hopper & Hopper to direct objects to dark chamber & 1 \\
        \hline
        Bearing Covers & Covers to protect bearings and prevent shafts from coming out & 4 \\
        \hline
    \end{tabular}
    \label{tab:2-piezas}
\end{table}

\clearpage
\section{Assembly Process}

\par First, place the 627zz bearings into the acrylic side supports in the 22mm holes, as shown in Figure \ref{fig:3-armado_1}. 

\begin{figure}[H]
    \centering
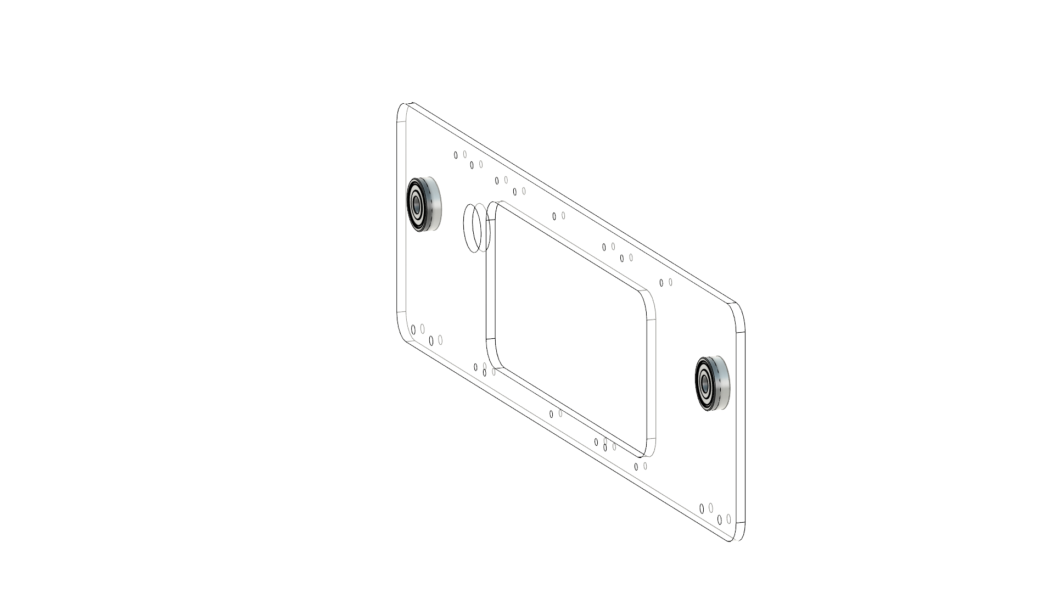
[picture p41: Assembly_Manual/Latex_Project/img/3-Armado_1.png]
    
    \caption{Rear acrylic support with embedded bearings. Glue is recommended for a press-fit.}
    \label{fig:3-Armado_1}
\end{figure}

\par The bearings should protrude toward the interior of the conveyor belt, according to Figure \ref{fig:3-armado_2}.

\begin{figure}[H]
    \centering
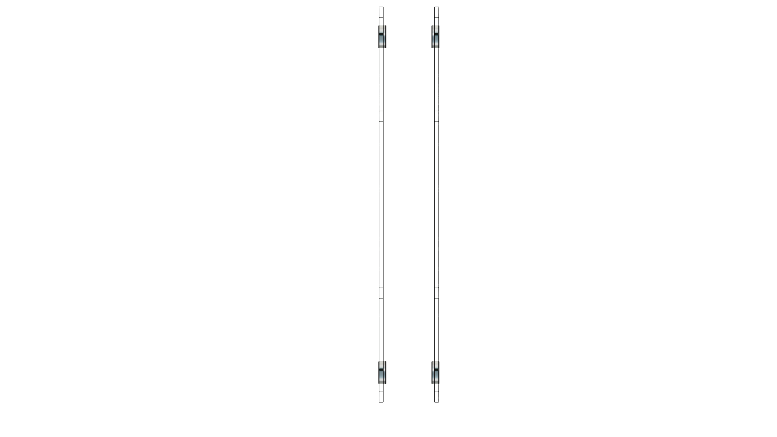
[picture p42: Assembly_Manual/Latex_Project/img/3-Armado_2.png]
    
    \caption{Acrylic supports with bearings positioned in the final conveyor belt assembly.}
    \label{fig:3-Armado_2}
\end{figure}

\par Next, to facilitate assembly, bolt the components from the rear side and then join with the other acrylic support. Attach the front and rear motor gears to the DC motor along with the motor mount, forming the \textbf{power unit} shown in Figure \ref{fig:3-Armado_3}.

\begin{figure}[H]
    \centering
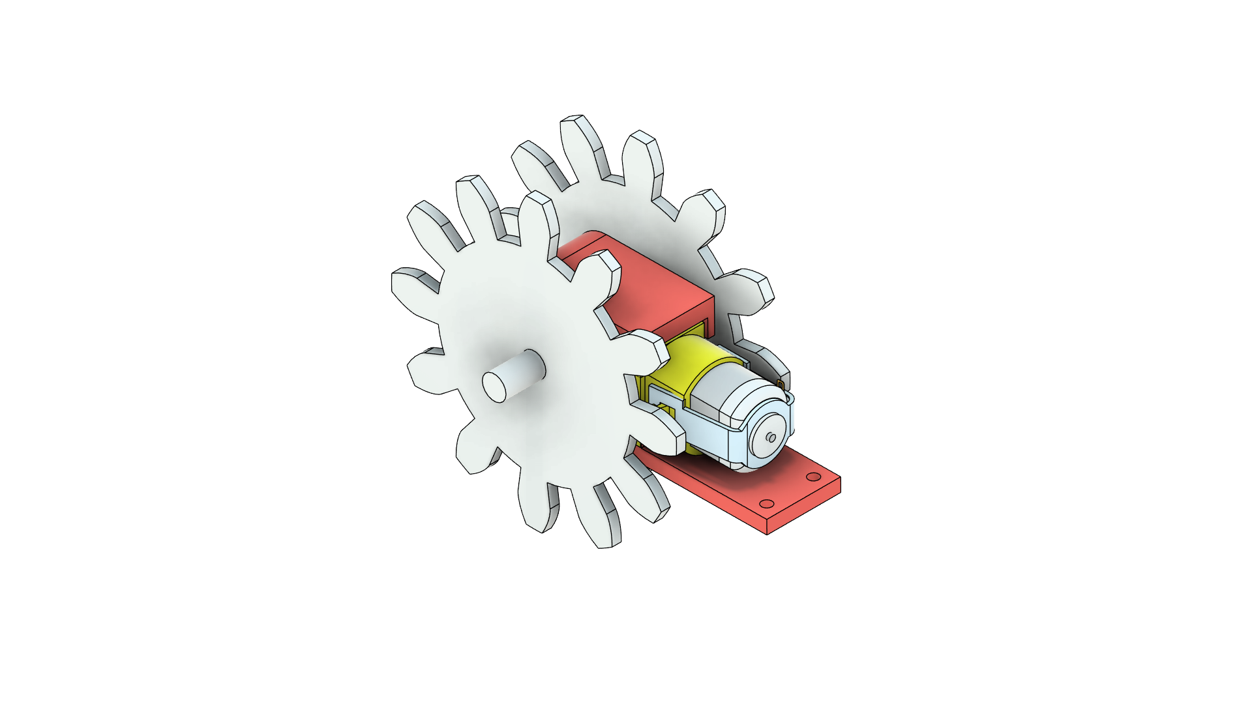
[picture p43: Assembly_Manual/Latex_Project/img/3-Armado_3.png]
    
    \caption{Assembled conveyor belt power unit, no additional fasteners required.}
    \label{fig:3-Armado_3}
\end{figure}

\par Then, insert the power unit into the left bearing of the rear side support using the shaft protruding from the gear, as shown in Figure \ref{fig:3-Armado_4}.

\begin{figure}[H]
    \centering
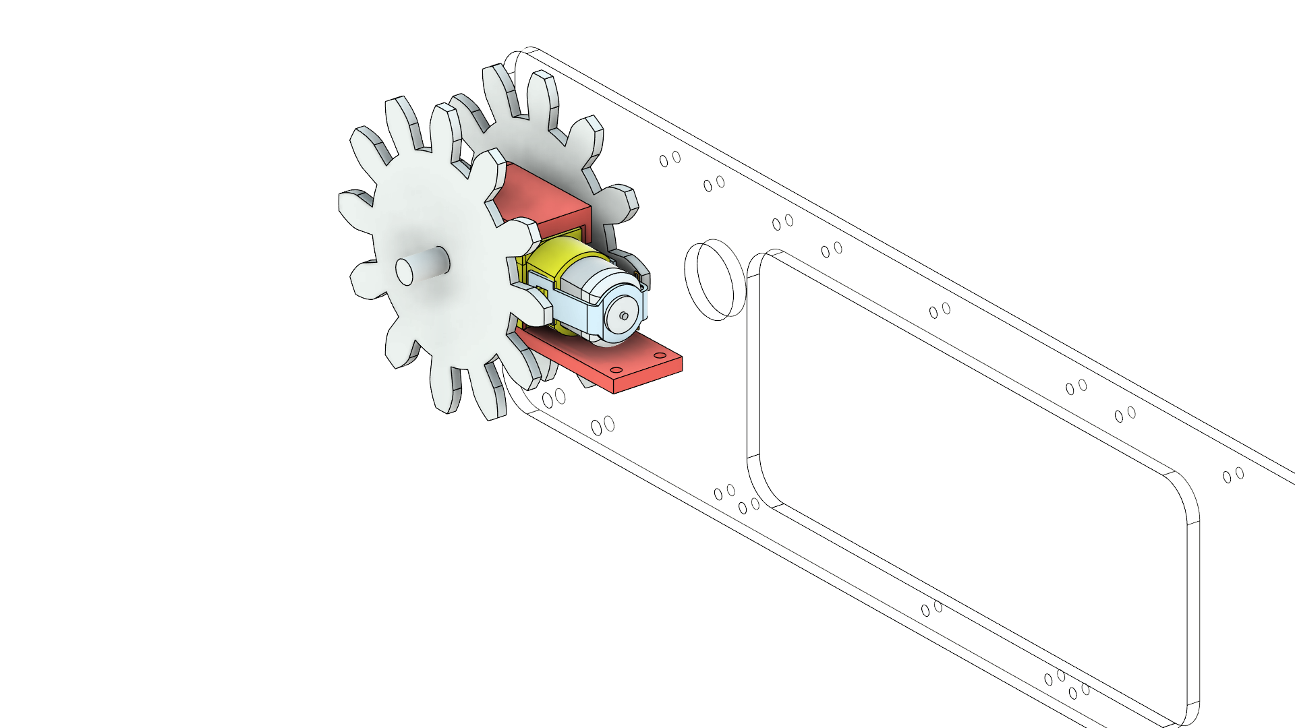
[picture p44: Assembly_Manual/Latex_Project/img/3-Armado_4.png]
    
    \caption{Power unit installed.}
    \label{fig:3-Armado_4}
\end{figure}

\par To secure the power unit, attach the lower support to the two lower 3mm holes near the unit, as shown in Figure \ref{fig:3-Armado_5}. 

\begin{figure}[H]
    \centering
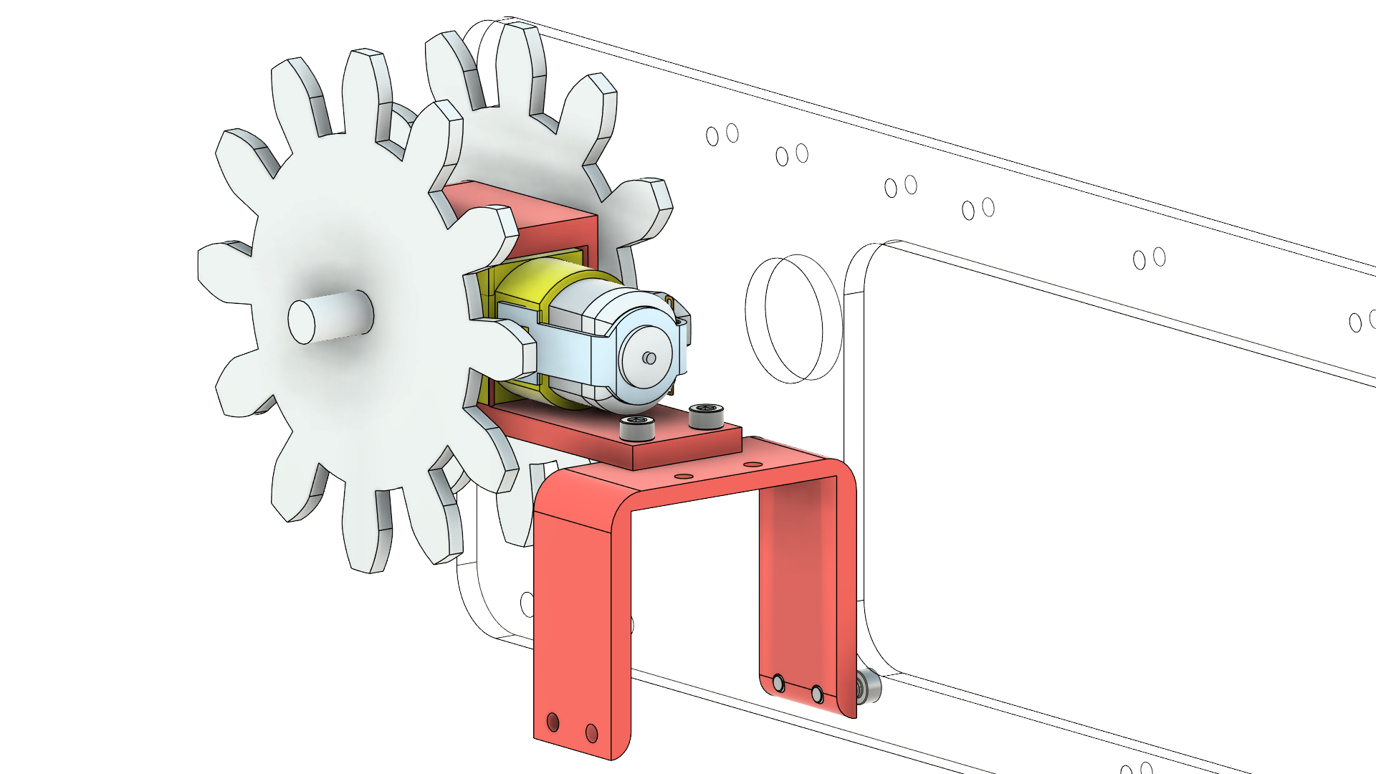
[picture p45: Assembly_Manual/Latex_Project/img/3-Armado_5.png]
    
    \caption{Power unit bolted with lower support.}
    \label{fig:3-Armado_5}
\end{figure}

\par Repeat this step for the lower support on the other side of the acrylic support, see Figure \ref{fig:3-Armado_6}.

\begin{figure}[H]
    \centering
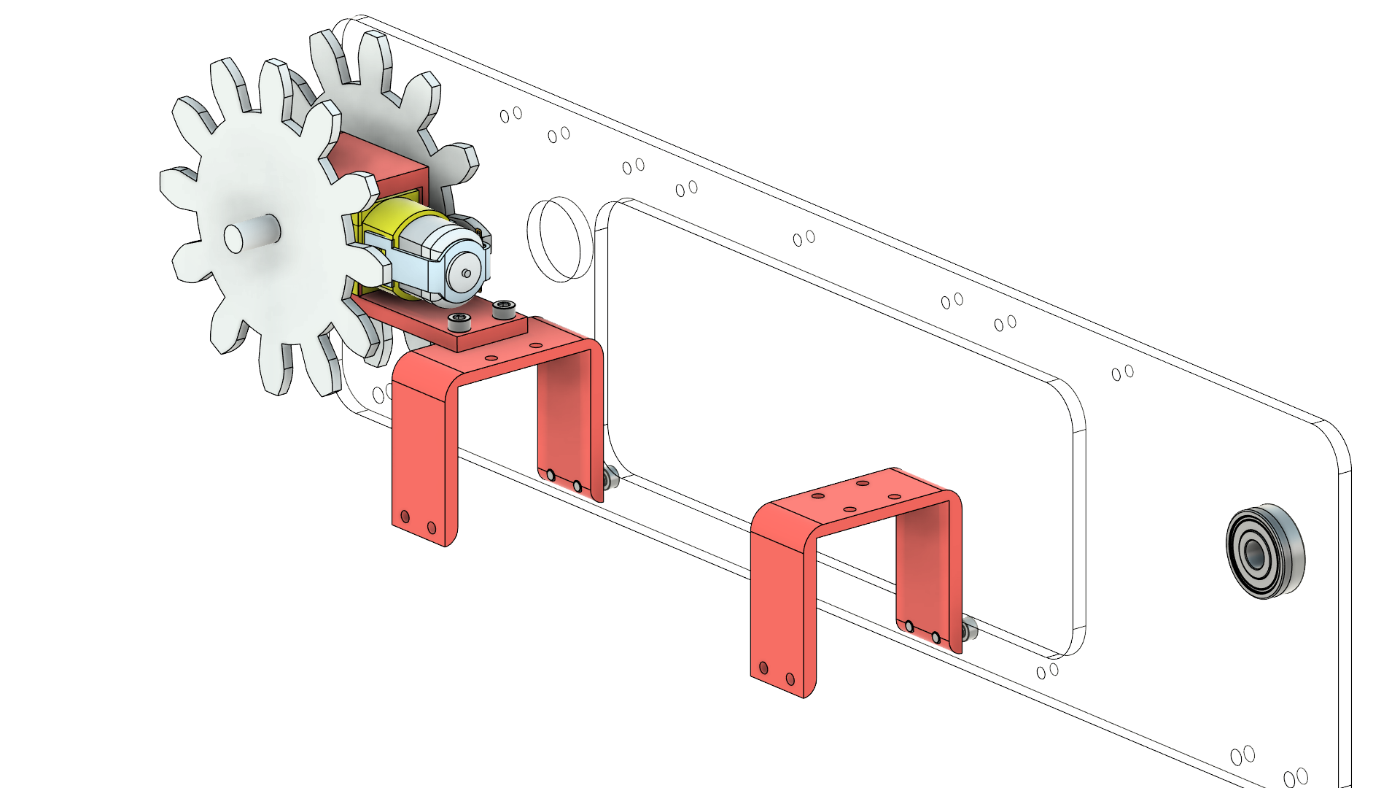
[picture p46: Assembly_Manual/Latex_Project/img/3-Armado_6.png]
    
    \caption{Lower supports bolted to acrylic support.}
    \label{fig:3-Armado_6}
\end{figure}

\par The component plate should be bolted together with the L298N driver using M3x8mm bolts and the 2x18650 battery holder using M3x4mm flat head bolts to allow battery placement, see Figure \ref{fig:3-Armado_7}.

\begin{figure}[H]
    \centering
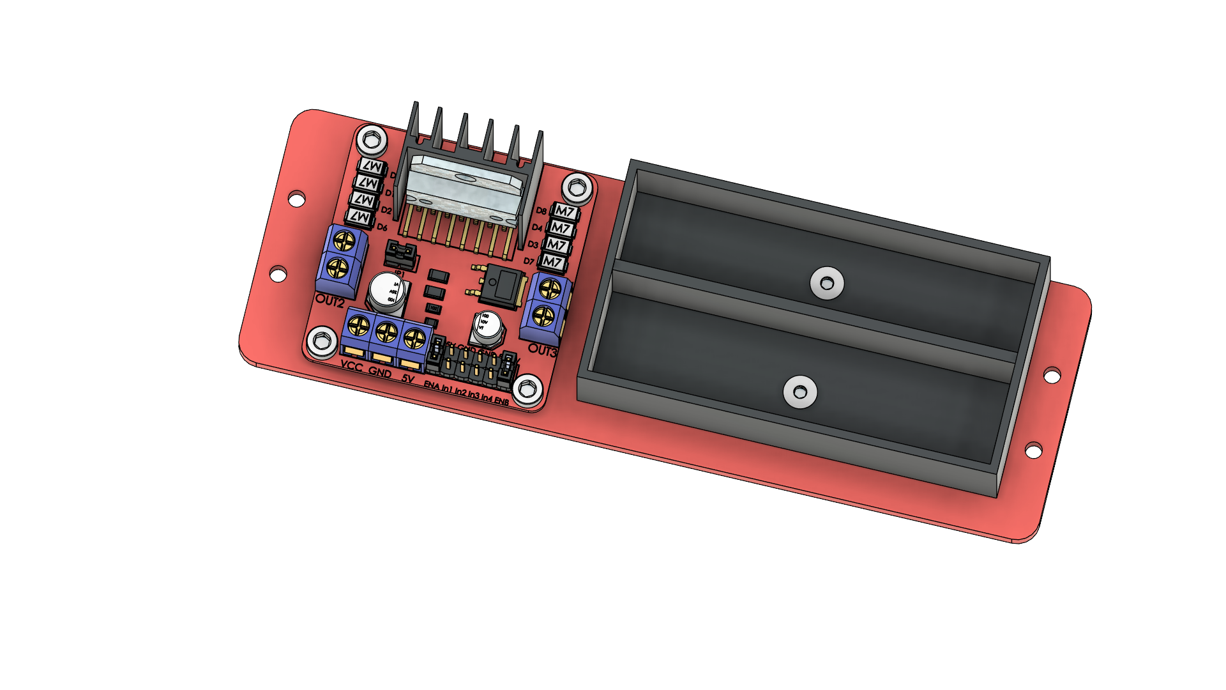
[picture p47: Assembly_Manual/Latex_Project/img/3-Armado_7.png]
    
    \caption{Assembled component plate.}
    \label{fig:3-Armado_7}
\end{figure}

\par Next, attach the component plate to the assembly by bolting it to both lower supports, as shown in Figure \ref{fig:3-Armado_8}.

\begin{figure}[H]
    \centering
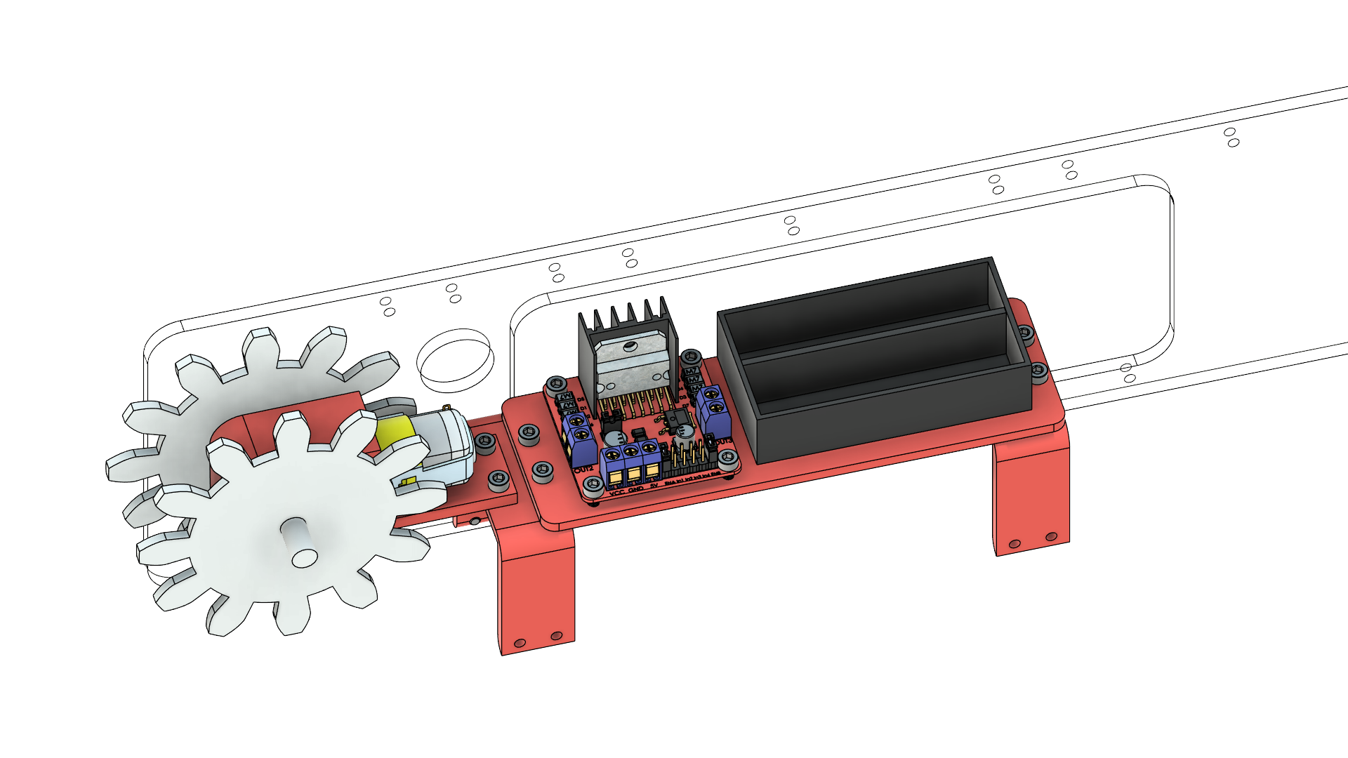
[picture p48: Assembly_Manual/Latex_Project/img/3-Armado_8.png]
    
    \caption{Component plate incorporated into the conveyor belt assembly.}
    \label{fig:3-Armado_8}
\end{figure}

\par \textbf{IMPORTANT:} After this step, check the initial connections of the DC motor, L298N driver, and power supply. Leave an extra wire available for the future connection of the SPST switch. Immediately connect the three control pins of the DC motor (ENA, IN1, and IN2). Also, reserve a wire for the 5V and GND return to power the servomotors. \\

\par Next, incorporate the \textbf{support unit} of the conveyor belt, consisting of the 7mm shaft and cylinder. Press-fit the 7mm shaft into the bearing opposite the power unit and place the cylinder inside the shaft, as shown in Figure \ref{fig:3-Armado_9}.

\begin{figure}[H]
    \centering
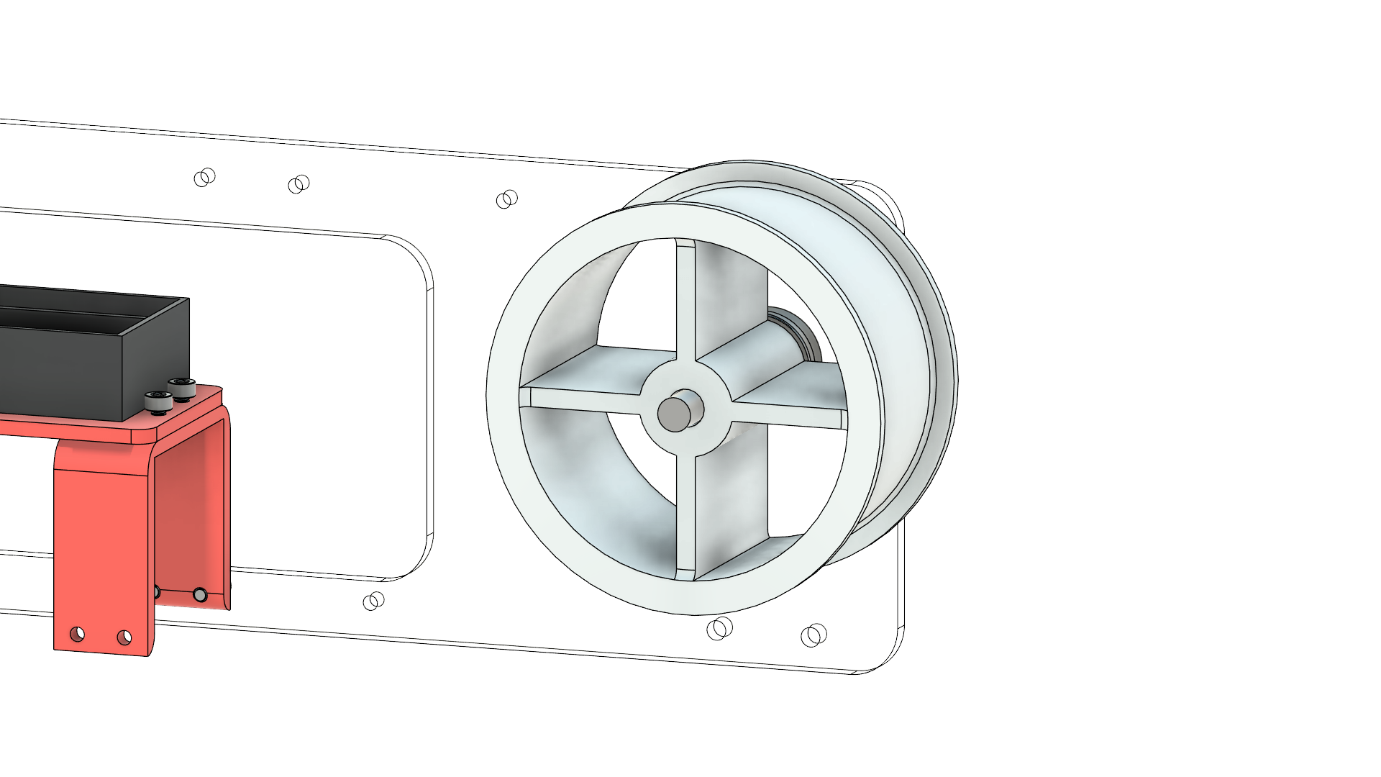
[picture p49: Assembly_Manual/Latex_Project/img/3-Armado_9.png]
    
    \caption{Support unit installed into the conveyor belt.}
    \label{fig:3-Armado_9}
\end{figure}

\par To complete the rear side acrylic support, place the servomotors into the upper holes of the acrylic supports. First, attach the servos without horns to the supports using M3 bolts, see Figure \ref{fig:3-Armado_10}. Pass the cables through the cutout in the support before positioning.

\begin{figure}[H]
    \centering
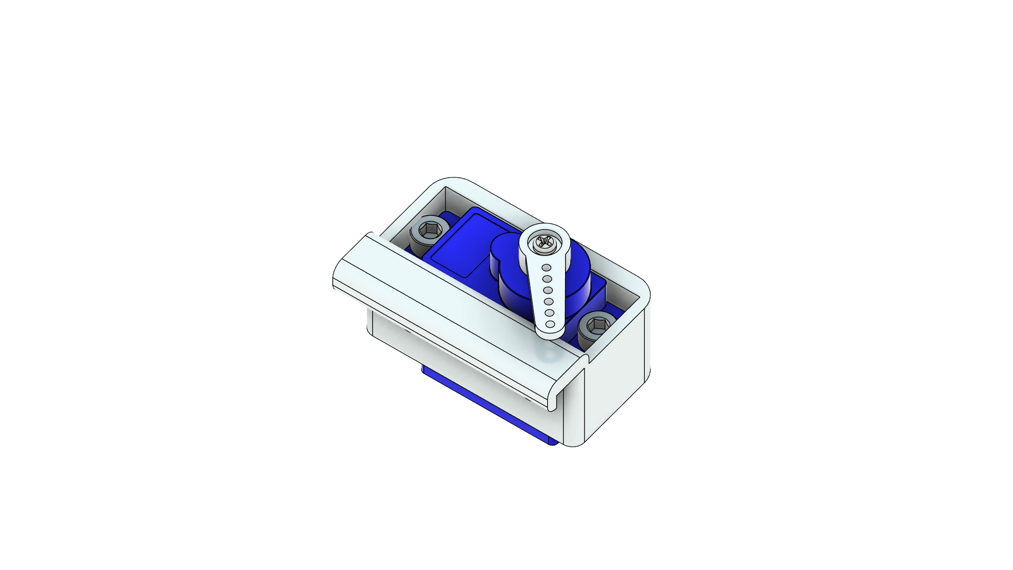
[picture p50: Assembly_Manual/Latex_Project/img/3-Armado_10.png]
    
    \caption{Servo mount with SG90 servo bolted.}
    \label{fig:3-Armado_10}
\end{figure}

\par Then, attach both servomotors to the current assembly, as illustrated in Figure \ref{fig:3-Armado_11}.

\begin{figure}[H]
    \centering
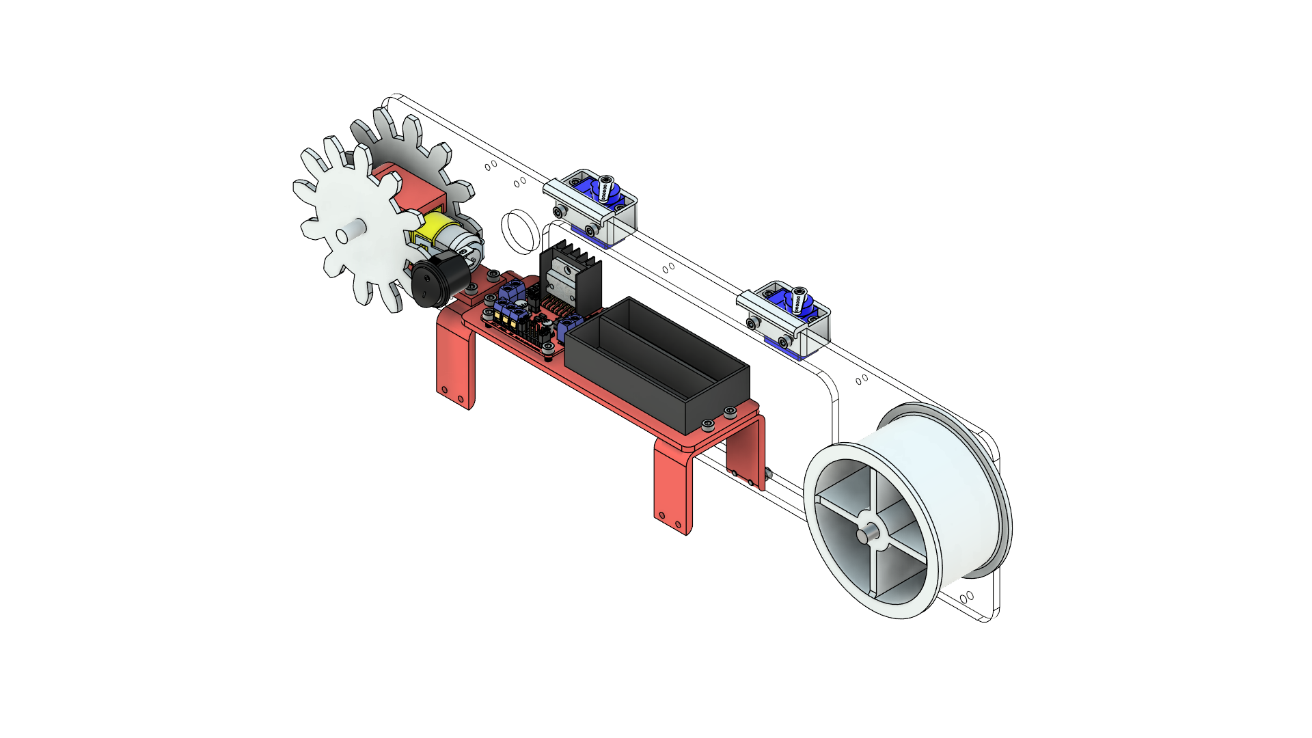
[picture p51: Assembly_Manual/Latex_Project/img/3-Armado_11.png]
    
    \caption{Servomotors installed in the conveyor belt assembly.}
    \label{fig:3-Armado_11}
\end{figure}

\par Finally, add the side wall supports to both acrylic supports using M4x8mm bolts, see Figure \ref{fig:3-Armado_12}.

\begin{figure}[H]
    \centering
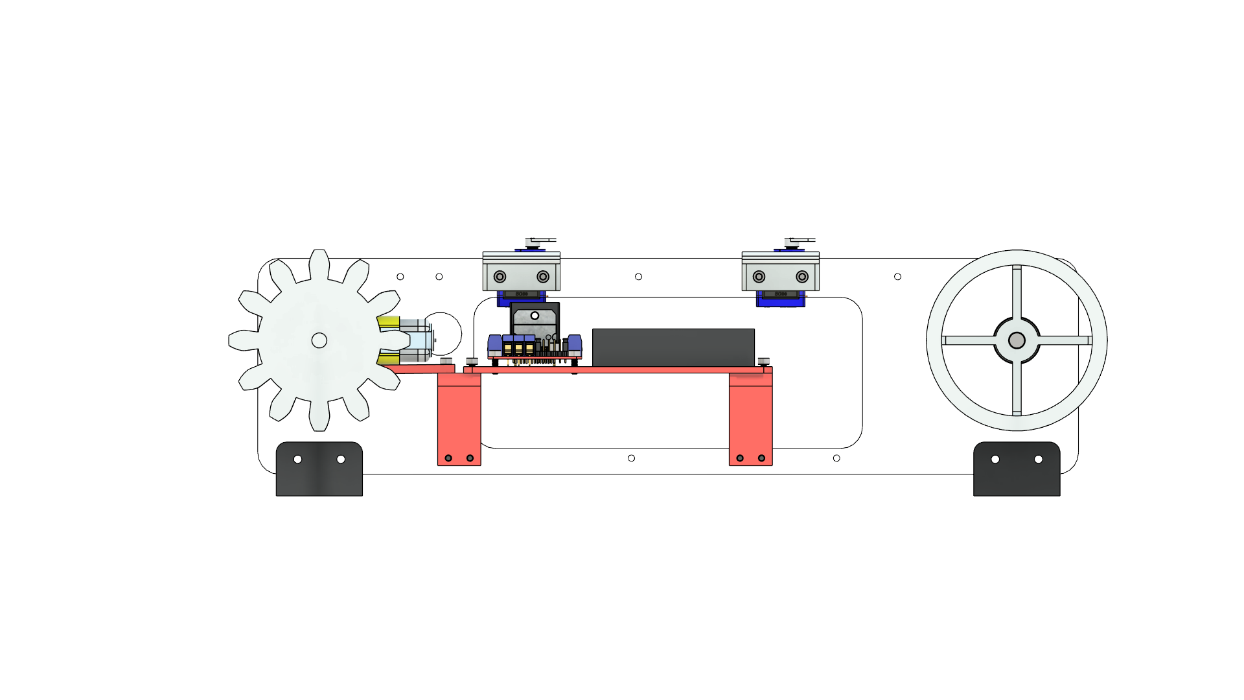
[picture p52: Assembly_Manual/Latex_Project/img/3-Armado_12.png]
    
    \caption{Side wall supports attached to the acrylic support.}
    \label{fig:3-Armado_12}
\end{figure}

\par Next, carefully place the track chain between the teeth of the power unit gears and over the cylinder of the support unit, according to Figure \ref{fig:3-Armado_13}.

\begin{figure}[H]
    \centering
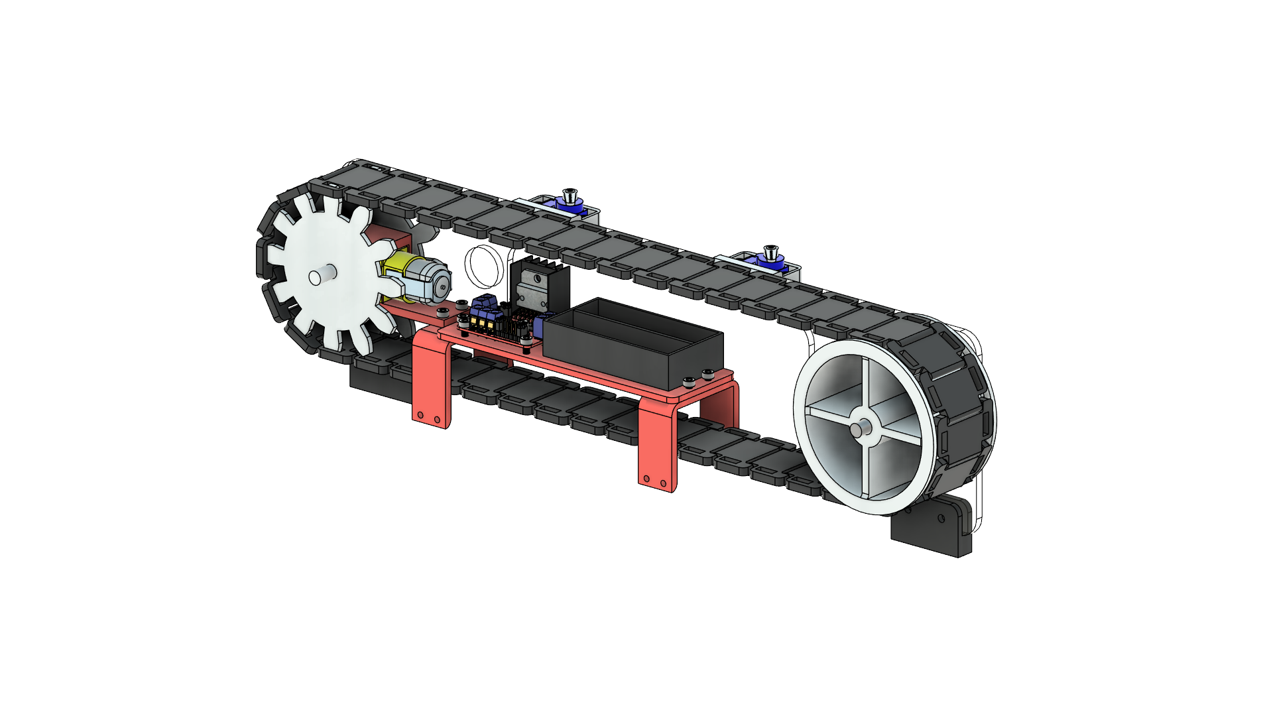
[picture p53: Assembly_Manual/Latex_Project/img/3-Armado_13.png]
    
    \caption{Track chain installed in the assembly.}
    \label{fig:3-Armado_13}
\end{figure}

\par Then, place the remaining side acrylic support over the shafts of the power unit and support unit, and bolt the lower supports to the acrylic support, as shown in Figure \ref{fig:3-Armado_14}.

\begin{figure}[H]
    \centering
    
    \caption{Remaining side acrylic support installed.}
    \label{fig:3-Armado_14}
\end{figure}

\par \textbf{IMPORTANT:} At this stage, connect the 2-pin SPST switch using the previously reserved wire, attaching it to the positive terminal of the batteries to control the conveyor belt power. Route the servomotor connections through the opposite hole of the switch support, ensuring all wires face the front of the conveyor for future connections. The switch installed in the 20mm hole is shown in Figure \ref{fig:3-Armado_15}.

\begin{figure}[H]
    \centering
    
    \caption{2-pin SPST switch installed in the assembly.}
    \label{fig:3-Armado_15}
\end{figure}

\par Next, place the bearing covers over the 4 bearings. These covers include pre-attached 12x4mm neodymium magnets with glue, as shown in Figure \ref{fig:3-Armado_16}.

\begin{figure}[H]
    \centering
    
    \caption{Bearing covers installed.}
    \label{fig:3-Armado_16}
\end{figure}

\par Then, attach the servo blades (remember to calibrate the zero position of the servos before installation to ensure correct operation range), see Figure \ref{fig:3-Armado_17}.

\begin{figure}[H]
    \centering
    
    \caption{Servo blades installed.}
    \label{fig:3-Armado_17}
\end{figure}

\par Next, assemble the dark chamber with the color sensor and the slat curtains before installing it on the conveyor belt. First, position the slat curtains into the upper holes of the chamber, as shown in Figure \ref{fig:3-Armado_18}.

\begin{figure}[H]
    \centering
    
    \caption{Slat curtains positioned in the dark chamber.}
    \label{fig:3-Armado_18}
\end{figure}

\par Then, bolt the GY-31/TCS3200 color sensor into the chamber using M3 bolts through the slat curtains, as shown in Figure \ref{fig:3-Armado_19}. Note the cutouts for the sensor connection pins at the top of the chamber.

\begin{figure}[H]
    \centering
    
    \caption{Color sensor GY-31/TCS3200 installed in the dark chamber.}
    \label{fig:3-Armado_19}
\end{figure}

\par After securing the sensor, bolt the dark chamber to the conveyor belt on the side holes, as illustrated in Figure \ref{fig:3-Armado_20}. M3x10mm bolts with nuts are recommended for better adjustment, but M3x8mm bolts also work.

\begin{figure}[H]
    \centering
    
    \caption{Dark chamber installed on the conveyor belt.}
    \label{fig:3-Armado_20}
\end{figure}

\par Next, attach the loading hopper to the protrusions on the sides of the dark chamber, as shown in Figure \ref{fig:3-Armado_21}.

\begin{figure}[H]
    \centering
    
    \caption{Loading hopper attached to the dark chamber.}
    \label{fig:3-Armado_21}
\end{figure}

\par Finally, attach the side receiving boxes along with the top support. First, pre-fix the receiving boxes with the top support for stability, as shown in Figure \ref{fig:3-Armado_22}.

\begin{figure}[H]
    \centering
    
    \caption{Side receiving box pre-fixed with top support.}
    \label{fig:3-Armado_22}
\end{figure}

\par Then, slightly lift the track chain and slide both receiving boxes onto the pre-fixed top support. Ensure they do not interfere with the servomotors. Attach M3 bolts to the three holes on the top support (2 front, 1 back), as shown in Figures \ref{fig:3-Armado_23} and \ref{fig:3-Armado_24}.

\begin{figure}[H]
    \centering
    
    \caption{Receiving boxes and top support assembly, front view.}
    \label{fig:3-Armado_23}
\end{figure}

\begin{figure}[H]
    \centering
    
    \caption{Receiving boxes and top support assembly, rear view.}
    \label{fig:3-Armado_24}
\end{figure}

\par Optionally, tensioners can be installed on the lower part of the conveyor belt next to each lower support. This ensures proper tension so the track chain engages with the power unit gears and moves correctly. To install the tensioners, lift the return section of the chain, place the tensioners, and bolt them at their single attachment point, as shown in Figure \ref{fig:3-Armado_25}.

\begin{figure}[H]
    \centering
    
    \caption{Tensioners bolted to the conveyor belt. The track chain is hidden in the CAD model as its bending occurs only in reality.}
    \label{fig:3-Armado_25}
\end{figure}

\par Additionally, the final receiving box at the end of the conveyor is optional, as shown at the beginning of this manual in Figure \ref{fig:1-Correa_armada}.

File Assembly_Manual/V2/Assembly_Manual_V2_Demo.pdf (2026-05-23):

University of Chile
Facultad de Ciencias Físicas y Matemáticas Department of Mechanical Engineering ME4250 – Mecatrónica

# Manual de Armado (preliminar)

Documentation "Desafío 2"

Profesor: Harold Valenzuela Auxiliar: Fernando Navarrete Ayudantes: Valentina Abarca, Emilia Gutiérrez

## 1. Introducción

¡Gracias por elegir la Correa Transportadora Clasificadora de REPOS! Diseñada por Fernando Navarrete, esta innovadora solución transforma la manera de clasificar objetos. Gracias a su avanzada detección de colores y la integración precisa de actuadores electromecánicos, podrás automatizar rutinas de clasificación de manera eficiente y confiable.

La Figura 1 muestra el sistema completamente armado, listo para optimizar tus procesos de clasificación. Su diseño permite manejar distintos tamaños y tipos de objetos, ajustando la velocidad y la secuencia de los actuadores según tus necesidades. Además, su construcción modular facilita el mantenimiento y futuras ampliaciones del sistema, asegurando un rendimiento constante y adaptable a diferentes entornos.


Figura 1: Correa Transportadora Clasificadora de Repos V2

En las siguientes secciones, se detallarán los pasos a seguir para armar su Correa Transporadora Clasificadora de REPOS.

Manual de Armado (preliminar) | 1

## 2. Listado de materiales y de piezas

Primero, se requieren los siguientes materiales para el armado de la correa transportadora, estos se detallan en la Tabla 1. CANTIDAD DE PERNOS POR CALCULAR

Tabla 1: Listado de materiales por correa

Nombre | Descripción | Cantidad
Pernos M3x8 | Pernos cabeza cilíndrica norma ISO M3 | -
Pernos M4x8 | Pernos cabeza cilíndrica norma ISO M4 | -
Pernos M3x4 | Pernos cabeza plana norma ISO M3 | -
Rodamientos 627zz | Rodamientos radiales norma SKF 7x22x7mm | 4
Motor Paso a Paso | Motor Stepper Nema 17 40cm | 1
EasyDriver A3967 | Controlador de motor Paso a Paso | 1
Sensor GY-31/TCS3200 | Sensor a color de 64 fotodiodos | 1
Servo SG90 | Servomotores modelo SG90 con horquillas | 2
Batería 18650 | Batería Ion de Litio formato 18650 de 3.7V | 3
Portapilas 3x18650 | Portapilas de Ion de Litio formato 18650 | 1
Switch SPST 2 pines | Switch SPST de 2 pines y 20mm de diametro | 1
Imanes de neodimio | Imanes de neodimio 12x4mm para tapas cubrerodamientos | 4
PCB Desafío 2 | Placa de circuito impreso para el Desafío 2 | 1
Buck Step-Down LM2596 | Regulador de Voltaje DC a DC | 1

Luego, el listado de piezas impresas necesario para ensamblar la correa transportadora, se muestra en la Tabla 2.

Tabla 2: Listado de piezas impresas en 3D para cada correa

Nombre | Descripción | Cantidad
Correa TPU dentada | Cadena dentada trapezoidal en V | 1
Polea Engranaje | Polea dentada de transmisión modificada | 1
Tornillo Helicoidal Nema | Tornillo Helicoidal 45o para el motor Nema 17 | 1
Soporte Motor | Pieza de soporte del motor Nema | 1
Polea Guía | Polea de guía sin dientes | 1
Eje 7mm | Eje de 7mm de la unidad de soporte y transmisión | 2
Soportes de acrílico | Soportes laterales de la correa de acrílico transparente | 2
Separador estructural inferior | Piezas de apoyo para los soportes laterales de acrílico | 2
Espaciador inferior | Pieza de soporte para portapilas | 2
Espaciador superior | Espaciador y soporte para racks y soporte motor nema | 2
Espaciador central | Pieza de soporte para correa y rack de cables | 1
Soporte servomotor | Soportes para servos SG90 | 2
Pala servomotores | Pala para empuje servos SG90 | 2
Caja receptoras | Cajas receptoras de objetos clasificados | 3
Rack de cables | Pieza de unión para ordenar cables en correa | 2
Cámara Oscura | Cámara oscurecida para sensor a color | 1
Cortinas de Lamas | Cortinas de lamas para cámara oscura | 2
Soporte PCB | Pieza impresa para soportar PCB Desafío 2 | 1
Tapas cubrerodamientos | Tapas para cubrir rodamientos y evitar que los ejes salgan | 4

## 3. Proceso de armado

POR ACTUALIZAR
Nota Feña: Antes que nada, Vale, Emi, deben desarmar la versión anterior, remover los rodamientos pegados con silicona caliente y limpiar con alcohol isopropílico las paredes de acrílico.

Primero, se deben colocar los rodamientos en las paredes de acrílico y fijar usando pegamento de cianoacrilato (gotita). Es importante que los rodamientos sobresalgan hacia el interior de la correa.


Figura 2: Pared de acrílico con rodamientos 627zz pegados.


Figura 3: Pared de acrílico con rodamientos 627zz pegados. Vista de detalle.

Posteriormente, deben fijar la pared trasera primero a los soportes estructurales inferiores con pernos M4.


Figura 4: Soportes estructurales inferiores sujetando pared de acrílico trasera.

Ahora, deben preparar el ensamblaje del sistema de potencia y transmisión de la correa, que irá en la parte de descarga de la correa. Deben primero insertar al motor Nema el tornillo helicoidal y fijarlo con un perno M3 pequeño al eje del motor.


Figura 5: Acople Tornillo helicoidal en el eje del motor Nema 17.

Posteriormente, deben colocar el motor sobre el soporte del motor nema con 4 pernos M3. Tener en consideración dejar los pines de alimentación orientados hacia afuera de la misma forma que se muestra en la imagen.


Figura 6: Fijación motor Nema 17 al soporte de motor.

Luego, deben anclar un espaciador superior a las dos roscas del soporte de motor nema para completar el apoyo.

Figura 7: Fijación soporte motor al espaciador superior.

Antes de montar el sistema de potencia, fijamos el eje de 7mm junto a la Polea engranaje en el


rodamiento con la pared de acrílico.

Figura 8: Colocación eje y Polea engranaje antes de montar sistema de potencia.

Proceda a montar el sistema armado anteriormente, debe colocarse en dirección desde arriba, hasta abajo, apoyando el tornillo del motor nema sobre el tornillo de la Polea engranaje.

Figura 9: Instalación sistema de potencia.


Tras este paso, debe añadir 3 pernos M3 a las fijaciones traseras del sistema instalado para evitar que se caiga momentáneamente.

Ahora, se procede a armar el sistema de manejo de cables y guía central de la correa. Para ello, debe unir las siguientes 3 piezas: Rack de cables, Espaciador central y Espaciador superior. Todo esto con pernos M3 cortos.

Figura 10: Armado soporte de manejo de cables.

Proceda a instalarlo sobre la pared de acrílico trasera y fijarlo con pernos M3.

Figura 11: Instalación soporte de manejo de cables.

Por otro lado, debe fijar un espaciador inferior junto al portapilas 3x18650 con pernos avellanados o de cabeza plana.


Figura 12: Fijación portapilas a espaciador inferior.

Luego, lo atornilla con pernos M3 por el otro lado de la pared acrílica trasera (mínimo 2). Debe cuidar que la orientación de los cables sea hacia el lado izquierdo de la correa (en contra del sistema de potencia).


Figura 13: Instalación espaciador inferior en pared acrílica trasera.

Nota: Deben colocar el otro espaciador inferior para brindar más soporte.
Como paso previo a la instalación de la correa, se recomienda acomodarla con la Polea guía.


Figura 14: Polea guía y correa transportadora.

De esta forma, debe insertarse el eje de la Polea guía en el rodamiento izquierdo y colocar cuidadosamente la correa hasta que quede montada y alineada con la Polea engranaje.

Figura 15: Polea guía y correa transportadora.

Tras este paso, procedemos a colocar la otra pared de acrílico con rodamientos. Nótese que puede colocarse de forma horizontal y cuidando de luego colocar los ejes sobre los rodamientos (puede que deba doblar un poco la pared de acrílico, tenga cuidado).


Figura 16: Sistema de correa armado.

Recuerde fijar los soportes con pernos M3 y M4 por la parte frontal, así la correa quedará correctamente alineada y fija. Solo omitir el perno frontal del Espaciador central.

Ahora, para evitar desplazamientos de ambos ejes, se usarán tapas con imanes de neodimio. Primero debe conseguir los imanes y pegarlos en las tapas.


Figura 17: Tapa de rodamiento con iman.

Debe preparar 4 por correa y luego insertarlos de forma simple en las paredes y gracias al magnetismo, se pegarán a los rodamientos. Advertencia: debe colocarlos suavemente, pueden romperse al impactar.

Figura 18: Tapa de rodamiento colocadas en la correa.


Tras este paso, queda colocar los accesorios electrónicos y de clasificación de la correa. Primero, se debe preparar la Cámara oscura junto al sensor de color. Sujételo con pernos por fuera.

Figura 19: Cámara Oscura con sensor a color adherido.

Luego, debe colocar las cortinas de lamas con 2 pernos c/u sobre la cámara oscura para restringir la luz externa.

Figura 20: Cámara Oscura ensamblada.

Para ensamblar la Cámara Oscura, debe estirar levemente la correa y ponerla por dentro de la cámara a través de la ranura central inferior (esto sirve para mantener la correa nivelada). Luego debe fijarla con 4 pernos M3. Debe cuidar que el lado del sensor esté mirando hacia atrás.


Figura 21: Cámara Oscura ensamblada en la correa.

Continuando el armado, el servomotor es simple de armar: se debe colocar en el soporte de servomotor y luego insertar la pala sobre el eje del servo.


Figura 22: Soporte servomotor y pala ensamblados.

Para cuestiones de ensamble, observe que ambos servomotores deben estar orientados a la derecha de la correa, por lo que deberá ensamblar ambos servomotores con orientación diferente. Para este ensamble, no se requieren pernos, deben ir colocados directamente sobre los soportes superiores.

Figura 23: Soporte servomotor y pala ensamblados en la correa.


Posteriormente, debe ensamblar la PCB del Desafío 2 sobre el Soporte PCB para anclarlo a la correa. Previamente deben estar todos los componentes y headers soldados.

Figura 24: Soporte PCB armado.

Luego, para ensamblarlo en la correa: fijar primero la pestaña inferior, luego girar y apoyar la rosca superior sobre el perno del espaciador central.

Figura 25: Soporte PCB ensamblado.

Finalmente, se deben gestionar las conexiones eléctricas y colocar el Switch de 2 pines y las cajas receptoras en las posiciones objetivos mostradas en la última imagen.


Figura 26: Correa Transportadora ensamblada.

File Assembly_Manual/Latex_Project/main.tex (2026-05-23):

% Template:     Auxiliar LaTeX
% Documento:    Archivo principal
% Versión:      8.0.0 (05/11/2021)
% Codificación: UTF-8
%
% Autor: Pablo Pizarro R.
%        pablo@ppizarror.com
%
% Manual template: [https://latex.ppizarror.com/auxiliares]
% Licencia MIT:    [https://opensource.org/licenses/MIT]

% CREACIÓN DEL DOCUMENTO
\documentclass[
	spanish, % Idioma: spanish, english, etc.
	letterpaper, oneside
]{article}

% INFORMACIÓN DEL DOCUMENTO
\def\documenttitle {Manual de Armado (preliminar)}
\def\documentsubject {Documentation "Desafío 2"}

\def\documentauthor {Fernando Navarrete}
\def\coursename {Mecatrónica}
\def\coursecode {ME4250}

\def\universityname {University of Chile}
\def\universityfaculty {Facultad de Ciencias Físicas y Matemáticas}
\def\universitydepartment {Department of Mechanical Engineering}
\def\universitydepartmentimage {departamentos/dimec}
\def\universitydepartmentimagecfg {height=1.75cm}
\def\universitylocation {Santiago de Chile}

% EQUIPO DOCENTE
\def\teachingstaff {
	\textbf{Profesor: Harold Valenzuela} \\
	Auxiliar: Fernando Navarrete \\
	Ayudantes: Valentina Abarca, Emilia Gutiérrez \\
}

% IMPORTACIÓN DEL TEMPLATE
\input{template}

% INICIO DE PÁGINAS
\begin{document}
	
% CONFIGURACIÓN DE PÁGINA Y ENCABEZADOS
\templatePagecfg

% ======================= INICIO DEL DOCUMENTO =======================

\input{Documento_ES}

% FIN DEL DOCUMENTO
\end{document}

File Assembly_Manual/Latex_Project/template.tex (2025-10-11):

% Template:     Auxiliar LaTeX
% Documento:    Núcleo del template
% Versión:      8.0.0 (05/11/2021)
% Codificación: UTF-8
%
% Autor: Pablo Pizarro R.
%        pablo@ppizarror.com
%
% Manual template: [https://latex.ppizarror.com/auxiliares]
% Licencia MIT:    [https://opensource.org/licenses/MIT]

% -----------------------------------------------------------------------------
% CONFIGURACIONES
% -----------------------------------------------------------------------------
% Definiciones previas
\def\iitembcirc {\raisebox{.55\height}{\scriptsize$\bullet$}}
\def\iitembsquare {\raisebox{.3\height}{\tiny$\blacksquare$}}
\def\iitemdash {\raisebox{.35\height}{\textendash}}
\def\iitemcirc {\raisebox{.25\height}{\small$\circ$}}
\def\iitemdiamond {\raisebox{.25\height}{\small$\diamond$}}

% Ajustes usuario
\input{template_config}

% -----------------------------------------------------------------------------
% IMPORTACIÓN DE LIBRERÍAS
% -----------------------------------------------------------------------------
% Se guardan variables antes de cargar librerías
\let\RE\Re
\let\IM\Im

% Parches de librerías
\let\counterwithout\relax
\let\counterwithin\relax
\let\underbar\relax
\let\underline\relax

% Si se desactiva el idioma
\def\unaccentedoperators {}
\def\decimalpoint {}
\def\bibname {}

% Parche de sectsty.sty
\makeatletter
\def\underline#1{\relax\ifmmode\@@underline{#1}\else $\@@underline{\hbox{#1}}\m@th$\relax\fi}
\def\underbar#1{\underline{\sbox\tw@{#1}\dp\tw@\z@\box\tw@}}
\makeatother

% -----------------------------------------------------------------------------
% Librerías del núcleo
% -----------------------------------------------------------------------------
% Manejo de condicionales
\usepackage{iftex}
\usepackage{ifthen}

% Verifica el tipo de compilador
\ifPDFTeX
	\def\compilertype {pdf2latex}
\else\ifXeTeX
	\def\compilertype {xelatex}
\else\ifLuaTeX
	\def\compilertype {lualatex}
\else
	\errmessage{Compilador no soportado}
	\stop
	\fi\fi
\fi

% Carga el idioma
\usepackage{tracklang}
\IfTrackedLanguage{spanish}{
	\usepackage[es-nosectiondot,es-lcroman,es-noquoting]{babel}
}{ % english, otros
	\usepackage{babel}
}

% Cambia el estilo de los títulos
\usepackage{sectsty}

% Codificación
\ifthenelse{\equal{\compilertype}{pdf2latex}}{
	\usepackage[utf8]{inputenc}}{
}

% Lanza un mensaje de error indicando mala configuración
%	#1	Parámetros opcionales (nostop,noheader)
%	#2	Mensaje de error
% 	#3	Configuración usada
%	#4	Valores esperados
\newcommand{\throwbadconfig}[4][]{
	\ifthenelse{\equal{#1}{noheader}}{
		\errmessage{LaTeX Warning: #4}
	}{
		\ifthenelse{\equal{#1}{noheader-nostop}}{
			\errmessage{LaTeX Warning: #4}
		}{
			\errmessage{LaTeX Warning: #2 (\noexpand #3= #3). Valores esperados: #4}
		}
	}
	\ifthenelse{\equal{#1}{nostop}}{}{
		\ifthenelse{\equal{#1}{noheader-nostop}}{}{
			\stop
		}
	}
}

% Librerías matemáticas
\ifthenelse{\equal{\equationleftalign}{true}}{
	\usepackage[fleqn]{amsmath}
}{
	\usepackage{amsmath}
}

% Tamaño de la fuente del documento
\usepackage{scrextend}
\usepackage{anyfontsize}
\changefontsizes{\documentfontsize pt}

% Evita error "Too many alphabets used in version normal"
\newcommand\hmmax {0}
\newcommand\bmmax {0}

% -----------------------------------------------------------------------------
% Librerías independientes
% -----------------------------------------------------------------------------
\usepackage{animate}       % Imágenes animadas
\usepackage{amsbsy}        % Símbolos matemáticos en negrita
\usepackage{amssymb}       % Librerías matemáticas
\usepackage{amsthm}        % Definición de teoremas
\usepackage{array}         % Nuevas características a las tablas
\usepackage{bigstrut}      % Líneas horizontales en tablas
\usepackage{bm}            % Caracteres en negrita en ecuaciones
\usepackage{booktabs}      % Permite manejar elementos visuales en tablas
\usepackage{caption}       % Leyendas
\usepackage{chngcntr}      % Añade números a las leyendas
\usepackage{color}         % Colores
\usepackage{datetime}      % Fechas
\usepackage{floatpag}      % Maneja estilos de páginas introducidos por objetos flotantes
\usepackage{floatrow}      % Permite administrar posiciones en los caption
\usepackage{framed}        % Permite creación de recuadros
\usepackage{gensymb}       % Simbología común
\usepackage{graphicx}      % Propiedades extra para los gráficos
\usepackage{lipsum}        % Permite crear párrafos de prueba
\usepackage{listings}      % Permite añadir código fuente
\usepackage{longtable}     % Permite utilizar tablas en varias hojas
\usepackage{mathtools}     % Permite utilizar notaciones matemáticas
\usepackage{multicol}      % Múltiples columnas
\usepackage{needspace}     % Maneja los espacios en página
\usepackage{pdflscape}     % Modo página horizontal de página
\usepackage{pdfpages}      % Permite administrar páginas en pdf
\usepackage{physics}       % Paquete de matemáticas
\usepackage{realboxes}     % Permite inserción de recuadros
\usepackage{rotating}      % Permite rotación de objetos
\usepackage{selinput}      % Compatibilidad con acentos
\usepackage{setspace}      % Cambia el espacio entre líneas
\usepackage{soul}          % Permite subrayar texto
\usepackage{stfloats}      % Permite cambiar posición de flotantes con [b] y [t]
\usepackage{subfig}        % Permite agrupar imágenes
\usepackage{textcomp}      % Simbología común
\usepackage{wrapfig}       % Posición de imágenes
\usepackage{xspace}        % Administra espacios en párrafos y líneas
\usepackage{xurl}          % Permite añadir enlaces

% -----------------------------------------------------------------------------
% Librerías con parámetros
% -----------------------------------------------------------------------------
\usepackage[makeroom]{cancel} % Cancelar términos en fórmulas
\usepackage[inline]{enumitem} % Permite enumerar ítems
\usepackage[subfigure,titles]{tocloft} % Maneja entradas en el índice
\usepackage[figure,table,lstlisting]{totalcount} % Contador de objetos
\usepackage[normalem]{ulem} % Permite tachar y subrayar
\usepackage[nointegrals]{wasysym} % Contiene caracteres misceláneos
\usepackage[dvipsnames,table,usenames]{xcolor} % Paquete de colores avanzado

% -----------------------------------------------------------------------------
% Librerías condicionales
% -----------------------------------------------------------------------------
% Imágenes en modo draft
\ifthenelse{\equal{\graphicxdraft}{true}}{
	\usepackage[
		allfiguresdraft,
		filename,
		size={scriptsize},
		style={tt}
	]{draftfigure}}{
}

% Acepta codificación UTF-8 en código fuente
\ifthenelse{\equal{\compilertype}{pdf2latex}}{
	\usepackage{listingsutf8}}{
}

% Footnotes en dos columnas
\ifthenelse{\equal{\footnotetwocolumn}{true}}{
	\usepackage{dblfnote}}{
}

% Regla superior
\ifthenelse{\equal{\footnoterulepage}{true}}{
	\usepackage[bottom,hang]{footmisc} % Estilo pie de página
}{
	\usepackage[bottom,norule,hang]{footmisc}
}

% Referencias
\ifthenelse{\equal{\backrefpagecite}{true}}{
	\usepackage[pdfencoding=auto,psdextra,backref=page]{hyperref} % Enlaces, referencias
}{
	\usepackage[pdfencoding=auto,psdextra]{hyperref} % Enlaces, referencias
}
\ifthenelse{\equal{\stylecitereferences}{natbib}}{ % Formato citas natbib
	\usepackage[nottoc,notlof,notlot]{tocbibind}
	\ifthenelse{\equal{\natbibrefcitecompress}{true}}{
		\usepackage[sort&compress]{natbib}
	}{
		\usepackage{natbib}
	}
}{
\ifthenelse{\equal{\stylecitereferences}{apacite}}{ % Formato citas apacite
	\usepackage[nottoc,notlof,notlot]{tocbibind}
	\usepackage{apacite}
}{
\ifthenelse{\equal{\stylecitereferences}{bibtex}}{ % Formato citas bibtex
}{
\ifthenelse{\equal{\stylecitereferences}{custom}}{ % Formato citas custom
}{}}}
}

% Anexos/Apéndices
\usepackage{appendix} % Anexos/Apéndices

% Dimensiones y geometría del documento
\ifthenelse{\equal{\compilertype}{lualatex}}{ % En lualatex sólo se puede cambiar 1 vez el margen
	\usepackage[top=\pagemargintop cm,bottom=\pagemarginbottom cm,left=\pagemarginleft cm,right=\pagemarginright cm]{geometry}
}{ % pdf2latex, xelatex
	\usepackage{geometry}
}

% Notas en tablas
\ifthenelse{\equal{\tablenotesameline}{true}}{
	\usepackage[para]{threeparttable}
}{
	\usepackage{threeparttable}
}

% -----------------------------------------------------------------------------
% Librerías dependientes
% -----------------------------------------------------------------------------
\usepackage{bookmark}      % Administración de marcadores en pdf
\usepackage{fancyhdr}      % Encabezados y pie de páginas
\usepackage{float}         % Administrador de posiciones de objetos
\usepackage{hyperxmp}      % Etiquetas opcionales para el pdf compilado
\usepackage{multirow}      % Agrega nuevas opciones a las tablas
\usepackage{titlesec}      % Administración de títulos

% -----------------------------------------------------------------------------
% Tipografía del documento
% -----------------------------------------------------------------------------
% Tipografías clásicas
\ifthenelse{\equal{\fontdocument}{lmodern}}{
	\usepackage{lmodern}
}{
\ifthenelse{\equal{\fontdocument}{arial}}{
	\usepackage{helvet}
	\renewcommand{\familydefault}{\sfdefault}
}{
\ifthenelse{\equal{\fontdocument}{arial2}}{
	\usepackage{arial}
}{
\ifthenelse{\equal{\fontdocument}{times}}{
	\usepackage{mathptmx}
}{
\ifthenelse{\equal{\fontdocument}{mathptmx}}{
	\usepackage{mathptmx}
}{
\ifthenelse{\equal{\fontdocument}{helvet}}{
	\renewcommand{\familydefault}{\sfdefault}
	\usepackage[scaled=0.95]{helvet}
	\usepackage[helvet]{sfmath}
}{
\ifthenelse{\equal{\fontdocument}{opensans}}{
	\usepackage[default,scale=0.95]{opensans}
}{
\ifthenelse{\equal{\fontdocument}{mathpazo}}{
	\usepackage{mathpazo}
}{
\ifthenelse{\equal{\fontdocument}{cambria}}{
	\usepackage{caladea}
}{
\ifthenelse{\equal{\fontdocument}{libertine}}{
	\usepackage[libertine]{newtxmath}
	\usepackage[tt=false]{libertine}
}{
\ifthenelse{\equal{\fontdocument}{custom}}{
}{

% Otros (último: fbb el 08/08/2021 - https://tug.org/FontCatalogue/seriffonts.html)
\ifthenelse{\equal{\fontdocument}{accanthis}}{
	\usepackage{accanthis}
}{
\ifthenelse{\equal{\fontdocument}{alegreya}}{
	\usepackage{Alegreya}
	\renewcommand*\oldstylenums[1]{{\AlegreyaOsF #1}}
}{
\ifthenelse{\equal{\fontdocument}{alegreyasans}}{
	\usepackage[sfdefault]{AlegreyaSans}
	\renewcommand*\oldstylenums[1]{{\AlegreyaSansOsF #1}}
}{
\ifthenelse{\equal{\fontdocument}{algolrevived}}{
	\usepackage{algolrevived}
}{
\ifthenelse{\equal{\fontdocument}{almendra}}{
	\usepackage{almendra}
}{
\ifthenelse{\equal{\fontdocument}{antpolt}}{
	\usepackage{antpolt}
}{
\ifthenelse{\equal{\fontdocument}{antpoltlight}}{
	\usepackage[light]{antpolt}
}{
\ifthenelse{\equal{\fontdocument}{anttor}}{
	\usepackage[math]{anttor}
}{
\ifthenelse{\equal{\fontdocument}{anttorcondensed}}{
	\usepackage[condensed,math]{anttor}
}{
\ifthenelse{\equal{\fontdocument}{anttorlight}}{
	\usepackage[light,math]{anttor}
}{
\ifthenelse{\equal{\fontdocument}{anttorlightcondensed}}{
	\usepackage[light,condensed,math]{anttor}
}{
\ifthenelse{\equal{\fontdocument}{arev}}{
	\let\quarternote\relax
	\let\eighthnote\relax
	\usepackage{arev}
}{
\ifthenelse{\equal{\fontdocument}{arimo}}{
	\usepackage[sfdefault]{arimo}
	\renewcommand*\familydefault{\sfdefault}
}{
\ifthenelse{\equal{\fontdocument}{arvo}}{
	\usepackage{Arvo}
}{
\ifthenelse{\equal{\fontdocument}{baskervald}}{
	\usepackage{baskervald}
}{
\ifthenelse{\equal{\fontdocument}{baskervaldx}}{
	\usepackage[lf]{Baskervaldx}
	\usepackage[bigdelims,vvarbb]{newtxmath}
	\usepackage[cal=boondoxo]{mathalfa}
	\renewcommand*\oldstylenums[1]{\textosf{#1}}
}{
\ifthenelse{\equal{\fontdocument}{berasans}}{
	\usepackage[scaled]{berasans}
	\renewcommand*\familydefault{\sfdefault}
}{
\ifthenelse{\equal{\fontdocument}{beraserif}}{
	\usepackage{bera}
}{
\ifthenelse{\equal{\fontdocument}{biolinum}}{
	\usepackage{libertine}
	\renewcommand*\familydefault{\sfdefault}
}{
\ifthenelse{\equal{\fontdocument}{bitter}}{
	\usepackage{bitter}
}{
\ifthenelse{\equal{\fontdocument}{boisik}}{
	\let\div\relax
	\usepackage{boisik}
}{
\ifthenelse{\equal{\fontdocument}{bookman}}{
	\usepackage{bookman}
}{
\ifthenelse{\equal{\fontdocument}{cabin}}{
	\usepackage[sfdefault]{cabin}
	\renewcommand*\familydefault{\sfdefault}
}{
\ifthenelse{\equal{\fontdocument}{cabincondensed}}{
	\usepackage[sfdefault,condensed]{cabin}
	\renewcommand*\familydefault{\sfdefault}
}{
\ifthenelse{\equal{\fontdocument}{caladea}}{
	\usepackage{caladea}
}{
\ifthenelse{\equal{\fontdocument}{cantarell}}{
	\usepackage[default]{cantarell}
}{
\ifthenelse{\equal{\fontdocument}{carlito}}{
	\usepackage[sfdefault]{carlito}
	\renewcommand*\familydefault{\sfdefault}
}{
\ifthenelse{\equal{\fontdocument}{charterbt}}{
	\usepackage[bitstream-charter]{mathdesign}
}{
\ifthenelse{\equal{\fontdocument}{chivolight}}{
	\usepackage[familydefault,light]{Chivo}
}{
\ifthenelse{\equal{\fontdocument}{chivoregular}}{
	\usepackage[familydefault,regular]{Chivo}
}{
\ifthenelse{\equal{\fontdocument}{clara}}{
	\usepackage{clara}
}{
\ifthenelse{\equal{\fontdocument}{clearsans}}{
	\usepackage[sfdefault]{ClearSans}
	\renewcommand*\familydefault{\sfdefault}
}{
\ifthenelse{\equal{\fontdocument}{cochineal}}{
	\usepackage{cochineal}
}{
\ifthenelse{\equal{\fontdocument}{coelacanth}}{
	\usepackage[nf]{coelacanth}
	\let\oldnormalfont\normalfont
	\def\normalfont{\oldnormalfont\mdseries}
}{
\ifthenelse{\equal{\fontdocument}{coelacanthextralight}}{
	\usepackage[el,nf]{coelacanth}
	\let\oldnormalfont\normalfont
	\def\normalfont{\oldnormalfont\mdseries}
}{
\ifthenelse{\equal{\fontdocument}{coelacanthlight}}{
	\usepackage[l,nf]{coelacanth}
	\let\oldnormalfont\normalfont
	\def\normalfont{\oldnormalfont\mdseries}
}{
\ifthenelse{\equal{\fontdocument}{comfortaa}}{
	\usepackage[default]{comfortaa}
}{
\ifthenelse{\equal{\fontdocument}{comicneue}}{
	\usepackage[default]{comicneue}
}{
\ifthenelse{\equal{\fontdocument}{comicneueangular}}{
	\usepackage[default,angular]{comicneue}
}{
\ifthenelse{\equal{\fontdocument}{computerconcrete}}{
	\usepackage{concmath}
}{
\ifthenelse{\equal{\fontdocument}{computerconcreteeuler}}{
	\let\Re\relax
	\let\Im\relax
	\usepackage{beton}
	\usepackage{euler}
}{
\ifthenelse{\equal{\fontdocument}{computermodern}}{
}{
\ifthenelse{\equal{\fontdocument}{computermodernbright}}{
	\usepackage{cmbright}
}{
\ifthenelse{\equal{\fontdocument}{crimson}}{
	\usepackage{crimson}
}{
\ifthenelse{\equal{\fontdocument}{crimsonpro}}{
	\usepackage{CrimsonPro}
	\let\oldnormalfont\normalfont
	\def\normalfont{\oldnormalfont\mdseries}
}{
\ifthenelse{\equal{\fontdocument}{crimsonproextralight}}{
	\usepackage[extralight]{CrimsonPro}
	\let\oldnormalfont\normalfont
	\def\normalfont{\oldnormalfont\mdseries}
}{
\ifthenelse{\equal{\fontdocument}{crimsonprolight}}{
	\usepackage[light]{CrimsonPro}
	\let\oldnormalfont\normalfont
	\def\normalfont{\oldnormalfont\mdseries}
}{
\ifthenelse{\equal{\fontdocument}{crimsonpromedium}}{
	\usepackage[medium]{CrimsonPro}
	\let\oldnormalfont\normalfont
	\def\normalfont{\oldnormalfont\mdseries}
}{
\ifthenelse{\equal{\fontdocument}{cyklop}}{
	\usepackage{cyklop}
}{
\ifthenelse{\equal{\fontdocument}{dejavusans}}{
	\usepackage{DejaVuSans}
	\renewcommand*\familydefault{\sfdefault}
}{
\ifthenelse{\equal{\fontdocument}{dejavusanscondensed}}{
	\usepackage{DejaVuSansCondensed}
	\renewcommand*\familydefault{\sfdefault}
}{
\ifthenelse{\equal{\fontdocument}{domitian}}{
	\usepackage{mathpazo}
	\usepackage{domitian}
	\let\oldstylenums\oldstyle
}{
\ifthenelse{\equal{\fontdocument}{droidsans}}{
	\usepackage[defaultsans]{droidsans}
	\renewcommand*\familydefault{\sfdefault}
}{
\ifthenelse{\equal{\fontdocument}{electrum}}{
	\usepackage[lf]{electrum}
}{	
\ifthenelse{\equal{\fontdocument}{erewhon}}{
	\usepackage[proportional,scaled=1.064]{erewhon}
	\usepackage[erewhon,vvarbb,bigdelims]{newtxmath}
	\renewcommand*\oldstylenums[1]{\textosf{#1}}
}{
\ifthenelse{\equal{\fontdocument}{fbb}}{
	\usepackage{fbb}
}{
\ifthenelse{\equal{\fontdocument}{fetamont}}{
	\usepackage{fetamont}
	\renewcommand*\familydefault{\sfdefault}
}{
\ifthenelse{\equal{\fontdocument}{firasans}}{
	\usepackage[sfdefault]{FiraSans}
	\renewcommand*\familydefault{\sfdefault}
}{
\ifthenelse{\equal{\fontdocument}{firasansnewtxsf}}{
	\usepackage[sfdefault]{FiraSans}
	\usepackage{newtxsf}
}{
\ifthenelse{\equal{\fontdocument}{fourier}}{
	\usepackage{fourier}
}{
\ifthenelse{\equal{\fontdocument}{fouriernc}}{
	\usepackage{fouriernc}
}{
\ifthenelse{\equal{\fontdocument}{gfsartemisia}}{
	\let\textlozenge\relax
	\usepackage{gfsartemisia}
}{
\ifthenelse{\equal{\fontdocument}{gfsartemisiaeuler}}{
	\let\textlozenge\relax
	\let\Re\relax
	\let\Im\relax
	\usepackage{gfsartemisia-euler}
}{
\ifthenelse{\equal{\fontdocument}{heuristica}}{
	\usepackage{heuristica}
	\usepackage[heuristica,vvarbb,bigdelims]{newtxmath}
	\renewcommand*\oldstylenums[1]{\textosf{#1}}
}{
\ifthenelse{\equal{\fontdocument}{iwona}}{
	\usepackage[math]{iwona}
}{
\ifthenelse{\equal{\fontdocument}{iwonacondensed}}{
	\usepackage[condensed,math]{iwona}
}{
\ifthenelse{\equal{\fontdocument}{iwonalight}}{
	\usepackage[light,math]{iwona}
}{
\ifthenelse{\equal{\fontdocument}{iwonalightcondensed}}{
	\usepackage[light,condensed,math]{iwona}
}{
\ifthenelse{\equal{\fontdocument}{kerkis}}{
	\usepackage{kmath,kerkis}
}{
\ifthenelse{\equal{\fontdocument}{kurier}}{
	\usepackage[math]{kurier}
}{
\ifthenelse{\equal{\fontdocument}{kuriercondensed}}{
	\usepackage[condensed,math]{kurier}
}{
\ifthenelse{\equal{\fontdocument}{kurierlight}}{
	\usepackage[light,math]{kurier}
}{
\ifthenelse{\equal{\fontdocument}{kurierlightcondensed}}{
	\usepackage[light,condensed,math]{kurier}
}{
\ifthenelse{\equal{\fontdocument}{lato}}{
	\usepackage[default]{lato}
}{
\ifthenelse{\equal{\fontdocument}{libertinus}}{
	\usepackage{libertinus}
}{
\ifthenelse{\equal{\fontdocument}{librebaskerville}}{
	\usepackage{librebaskerville}
}{
\ifthenelse{\equal{\fontdocument}{librebodoni}}{
	\usepackage{LibreBodoni}
}{
\ifthenelse{\equal{\fontdocument}{librecaslon}}{
	\usepackage{librecaslon}
}{
\ifthenelse{\equal{\fontdocument}{libris}}{
	\usepackage{libris}
	\renewcommand*\familydefault{\sfdefault}
}{
\ifthenelse{\equal{\fontdocument}{lxfonts}}{
	\usepackage{lxfonts}
}{
\ifthenelse{\equal{\fontdocument}{merriweather}}{
	\usepackage[sfdefault]{merriweather}
}{
\ifthenelse{\equal{\fontdocument}{merriweatherlight}}{
	\usepackage[sfdefault,light]{merriweather}
}{
\ifthenelse{\equal{\fontdocument}{mintspirit}}{
	\usepackage[default]{mintspirit}
}{
\ifthenelse{\equal{\fontdocument}{mlmodern}}{
	\usepackage{mlmodern}
}{
\ifthenelse{\equal{\fontdocument}{montserratalternatesextralight}}{
	\usepackage[defaultfam,extralight,tabular,lining,alternates]{montserrat}
	\renewcommand*\oldstylenums[1]{{\fontfamily{Montserrat-TOsF}\selectfont #1}}
}{
\ifthenelse{\equal{\fontdocument}{montserratalternatesregular}}{
	\usepackage[defaultfam,tabular,lining,alternates]{montserrat}
	\renewcommand*\oldstylenums[1]{{\fontfamily{Montserrat-TOsF}\selectfont #1}}
}{
\ifthenelse{\equal{\fontdocument}{montserratalternatesthin}}{
	\usepackage[defaultfam,thin,tabular,lining,alternates]{montserrat}
	\renewcommand*\oldstylenums[1]{{\fontfamily{Montserrat-TOsF}\selectfont #1}}
}{
\ifthenelse{\equal{\fontdocument}{montserratextralight}}{
	\usepackage[defaultfam,extralight,tabular,lining]{montserrat}
	\renewcommand*\oldstylenums[1]{{\fontfamily{Montserrat-TOsF}\selectfont #1}}
}{
\ifthenelse{\equal{\fontdocument}{montserratlight}}{
	\usepackage[defaultfam,light,tabular,lining]{montserrat}
	\renewcommand*\oldstylenums[1]{{\fontfamily{Montserrat-TOsF}\selectfont #1}}
}{
\ifthenelse{\equal{\fontdocument}{montserratregular}}{
	\usepackage[defaultfam,tabular,lining]{montserrat}
	\renewcommand*\oldstylenums[1]{{\fontfamily{Montserrat-TOsF}\selectfont #1}}
}{
\ifthenelse{\equal{\fontdocument}{montserratthin}}{
	\usepackage[defaultfam,thin,tabular,lining]{montserrat}
	\renewcommand*\oldstylenums[1]{{\fontfamily{Montserrat-TOsF}\selectfont #1}}
}{
\ifthenelse{\equal{\fontdocument}{newpx}}{
	\usepackage{newpxtext,newpxmath}
}{
\ifthenelse{\equal{\fontdocument}{nimbussans}}{
	\usepackage{nimbussans}
	\renewcommand*\familydefault{\sfdefault}
}{
\ifthenelse{\equal{\fontdocument}{noto}}{
	\usepackage[sfdefault]{noto}
	\renewcommand*\familydefault{\sfdefault}
}{
\ifthenelse{\equal{\fontdocument}{notoserif}}{
	\usepackage{notomath}
}{
\ifthenelse{\equal{\fontdocument}{opensansserif}}{
	\usepackage[default,oldstyle,scale=0.95]{opensans}
}{
\ifthenelse{\equal{\fontdocument}{overlock}}{
	\usepackage[sfdefault]{overlock}
	\renewcommand*\familydefault{\sfdefault}
}{
\ifthenelse{\equal{\fontdocument}{paratype}}{
	\usepackage{paratype}
	\renewcommand*\familydefault{\sfdefault}
}{
\ifthenelse{\equal{\fontdocument}{paratypesanscaption}}{
	\usepackage{PTSansCaption}
	\renewcommand*\familydefault{\sfdefault}
}{
\ifthenelse{\equal{\fontdocument}{paratypesansnarrow}}{
	\usepackage{PTSansNarrow}
	\renewcommand*\familydefault{\sfdefault}
}{
\ifthenelse{\equal{\fontdocument}{pxfonts}}{
	\usepackage{pxfonts}
}{
\ifthenelse{\equal{\fontdocument}{quattrocento}}{
	\usepackage[sfdefault]{quattrocento}
}{
\ifthenelse{\equal{\fontdocument}{raleway}}{
	\usepackage[default]{raleway}
}{
\ifthenelse{\equal{\fontdocument}{ralewayblack}}{
	\usepackage[black]{raleway}
}{
\ifthenelse{\equal{\fontdocument}{ralewayextralight}}{
	\usepackage[extralight]{raleway}
}{
\ifthenelse{\equal{\fontdocument}{ralewaymedium}}{
	\usepackage[medium]{raleway}
}{
\ifthenelse{\equal{\fontdocument}{ralewaylight}}{
	\usepackage[light]{raleway}
}{
\ifthenelse{\equal{\fontdocument}{ralewaythin}}{
	\usepackage[thin]{raleway}
}{
\ifthenelse{\equal{\fontdocument}{roboto}}{
	\usepackage[sfdefault]{roboto}
}{
\ifthenelse{\equal{\fontdocument}{robotocondensed}}{
	\usepackage[sfdefault,condensed]{roboto}
}{
\ifthenelse{\equal{\fontdocument}{robotolight}}{
	\usepackage[sfdefault,light]{roboto}
}{
\ifthenelse{\equal{\fontdocument}{robotolightcondensed}}{
	\usepackage[sfdefault,light,condensed]{roboto}
}{
\ifthenelse{\equal{\fontdocument}{robotothin}}{
	\usepackage[sfdefault,thin]{roboto}
}{
\ifthenelse{\equal{\fontdocument}{rosario}}{
	\usepackage[familydefault]{Rosario}
}{
\ifthenelse{\equal{\fontdocument}{sourcesanspro}}{
	\usepackage[default]{sourcesanspro}
}{
\ifthenelse{\equal{\fontdocument}{step}}{
	\usepackage[notext]{stix}
	\usepackage{step}
}{
\ifthenelse{\equal{\fontdocument}{stickstoo}}{
	\usepackage{stickstootext}
	\usepackage[stickstoo,vvarbb]{newtxmath}
}{
\ifthenelse{\equal{\fontdocument}{texgyrebonum}}{
	\usepackage{tgbonum}
}{
\ifthenelse{\equal{\fontdocument}{txfonts}}{
	\usepackage{txfonts}
}{
\ifthenelse{\equal{\fontdocument}{uarial}}{
	\usepackage{uarial}
	\renewcommand*\familydefault{\sfdefault}
}{
\ifthenelse{\equal{\fontdocument}{ugq}}{
	\renewcommand*\sfdefault{ugq}
	\renewcommand*\familydefault{\sfdefault}
}{
\ifthenelse{\equal{\fontdocument}{universalis}}{
	\usepackage[sfdefault]{universalis}
}{
\ifthenelse{\equal{\fontdocument}{universaliscondensed}}{
	\usepackage[condensed,sfdefault]{universalis}
}{
\ifthenelse{\equal{\fontdocument}{venturis}}{
	\usepackage[lf]{venturis}
	\renewcommand*\familydefault{\sfdefault}
}{
	\throwbadconfig[nostop]{Fuente desconocida}{\fontdocument}{(Fuentes recomendadas) lmodern,carial,arial2,times,mathptmx,helvet,opensans,mathpazo,cambria,libertine,custom}
	\throwbadconfig[noheader-nostop]{Fuente desconocida}{\fontdocument}{(Fuentes adicionales) accanthis,alegreya,alegreyasans,algolrevived,almendra,antpolt,antpoltlight,anttor,anttorcondensed,anttorlight,anttorlightcondensed,arev,arimo,arvo,baskervald,baskervaldx,berasans,beraserif,biolinum,bitter,boisik,bookman,cabin,cabincondensed,cantarell,caladea,carlito,charterbt,chivolight,chivoregular,clara,clearsans,cochineal,coelacanth,coelacanthextralight,coelacanthlight,comfortaa,comicneue,comicneueangular,computerconcrete,computerconcreteeuler,computermodern,computermodernbright,crimson,crimsonpro,crimsonproextralight,crimsonprolight,crimsonpromedium,cyklop}
	\throwbadconfig[noheader-nostop]{Fuente desconocida}{\fontdocument}{dejavusans,dejavusanscondensed,domitian,droidsans,electrum,erewhon,fbb,fetamont,firasans,firasansnewtxsf,fourier,fouriernc,gfsartemisia,gfsartemisiaeuler,heuristica,iwona,iwonacondensed,iwonalight,iwonalightcondensed,kerkis,kurier,kuriercondensed,kurierlight,kurierlightcondensed,lato,libertinus,librebaskerville,librebodoni,librecaslon,libris,lxfonts}
	\throwbadconfig[noheader]{Fuente desconocida}{\fontdocument}{merriweather,merriweatherlight,mintspirit,mlmodern,montserratalternatesextralight,montserratalternatesregular,montserratalternatesthin,montserratextralight,montserratlight,montserratregular,montserratthin,newpx,nimbussans,noto,notoserif,opensansserif,overlock,paratype,paratypesanscaption,paratypesansnarrow,pxfonts,quattrocento,raleway,ralewayblack,ralewayextralight,ralewaymedium,ralewaylight,ralewaythin,roboto,robotolight,robotolightcondensed,robotothin,rosario,sourcesanspro,step,stickstoo,uarial,texgyrebonum,txfonts,ugq,universalis,universaliscondensed,venturis}
	}}}}}}}}}}}}}}}}}}}}}}}}}}}}}}}}}}}}}}}}}}}}}}}}}}}}}}}}}}}}}}}}}}}}}}}}}}}}}}}}}}}}}}}}}}}}}}}}}}}}}}}}}}}}}}}}}}}}}}}}}}}}}}}}}}}}}}
}

% -----------------------------------------------------------------------------
% Tipografía typewriter
% -----------------------------------------------------------------------------
% https://tug.org/FontCatalogue/typewriterfonts.html
\ifthenelse{\equal{\fonttypewriter}{custom}}{
}{
\ifthenelse{\equal{\fonttypewriter}{tmodern}}{
	\renewcommand*\ttdefault{lmvtt}
}{
\ifthenelse{\equal{\fonttypewriter}{anonymouspro}}{
	\usepackage[ttdefault=true]{AnonymousPro}
}{
\ifthenelse{\equal{\fonttypewriter}{ascii}}{
	\usepackage{ascii}
	\let\SI\relax
}{
\ifthenelse{\equal{\fonttypewriter}{beramono}}{
	\usepackage[scaled]{beramono}
}{
\ifthenelse{\equal{\fonttypewriter}{cascadiacode}}{
	\usepackage{cascadia-code}
}{
\ifthenelse{\equal{\fonttypewriter}{cmpica}}{
	\usepackage{addfont}
	\addfont{OT1}{cmpica}{\pica}
	\addfont{OT1}{cmpicab}{\picab}
	\addfont{OT1}{cmpicati}{\picati}
	\renewcommand*\ttdefault{pica}
}{
\ifthenelse{\equal{\fonttypewriter}{cmodern}}{
}{
\ifthenelse{\equal{\fonttypewriter}{courier}}{
	\usepackage{courier}
}{
\ifthenelse{\equal{\fonttypewriter}{courier10}}{
	\usepackage{courierten}
}{
\ifthenelse{\equal{\fonttypewriter}{cmvtt}}{
	\renewcommand*\ttdefault{cmvtt}
}{
\ifthenelse{\equal{\fonttypewriter}{dejavusansmono}}{
	\usepackage[scaled]{DejaVuSansMono}
}{
\ifthenelse{\equal{\fonttypewriter}{droidsansmono}}{
	\usepackage[defaultmono]{droidsansmono}
}{
\ifthenelse{\equal{\fonttypewriter}{firamono}}{
	\usepackage[scale=0.85]{FiraMono}
}{
\ifthenelse{\equal{\fonttypewriter}{gomono}}{
	\usepackage[scale=0.85]{GoMono}
}{
\ifthenelse{\equal{\fonttypewriter}{inconsolata}}{
	\usepackage{inconsolata}
}{
\ifthenelse{\equal{\fonttypewriter}{nimbusmono}}{
	\usepackage{nimbusmono}
}{
\ifthenelse{\equal{\fonttypewriter}{newtxtt}}{
	\usepackage[zerostyle=d]{newtxtt}
}{
\ifthenelse{\equal{\fonttypewriter}{nimbusmono}}{
	\usepackage{nimbusmono}
}{
\ifthenelse{\equal{\fonttypewriter}{nimbusmononarrow}}{
	\usepackage{nimbusmononarrow}
}{
\ifthenelse{\equal{\fonttypewriter}{lcmtt}}{
	\renewcommand*\ttdefault{lcmtt}
}{
\ifthenelse{\equal{\fonttypewriter}{sourcecodepro}}{
	\usepackage[ttdefault=true,scale=0.85]{sourcecodepro}
}{
\ifthenelse{\equal{\fonttypewriter}{texgyrecursor}}{
	\usepackage{tgcursor}
}{
\ifthenelse{\equal{\fonttypewriter}{txtt}}{
	\renewcommand*\ttdefault{txtt}
}{
	\throwbadconfig{Fuente desconocida}{\fonttypewriter}{custom,anonymouspro,ascii,beramono,cascadiacode,cmpica,cmodern,courier,courier10,cvmtt,dejavusansmono,droidsansmono,firamono,gomono,inconsolata,kpmonospaced,lcmtt,newtxtt,nimbusmono,nimbusmononarrow,texgyrecursor,tmodern,txtt}
	}}}}}}}}}}}}}}}}}}}}}}}
}

% -----------------------------------------------------------------------------
% Finales
% -----------------------------------------------------------------------------
\usepackage[T1]{fontenc} % Caracteres acentuados
\ifthenelse{\equal{\showlayoutlines}{true}}{ % Muestra las líneas del layout
	\usepackage{showframe}}{
}
\ifthenelse{\equal{\showlinenumbers}{true}}{ % Muestra los números de línea
	\usepackage[switch,columnwise,running]{lineno}}{
}
\usepackage{csquotes} % Citas y comillas
\ifthenelse{\equal{\compilertype}{pdf2latex}}{
	\inputencoding{utf8}}{
}

% -----------------------------------------------------------------------------
% IMPORTACIÓN DE FUNCIONES Y ENTORNOS
% -----------------------------------------------------------------------------
% Definición de variables globales
\global\def\GLOBALcaptiondefn {EMPTY-VAR}         % Definición del caption
\global\def\GLOBALchapternumenabled {false}       % Numeración de capítulos empezó
\global\def\GLOBALenvappendix {false}             % Indica que el entorno anexo está activo
\global\def\GLOBALenvimageadded {false}           % Indica que una imagen ha sido añadida
\global\def\GLOBALenvimageinitialized {false}     % Entorno images activo
\global\def\GLOBALenvmulticol {false}             % Indica que el entorno multicol está activo
\global\def\GLOBALsectionanumenabled {false}      % Sección sin numeración
\global\def\GLOBALsubsectionanumenabled {false}   % Subsección sin numeración
\global\def\GLOBALsubsubsectionanumenabled{false} % Sub-subsección sin numeración
\global\def\GLOBALtablerowcolorindex {2}          % Índice tabla colores
\global\def\GLOBALtablerowcolorswitch {false}     % Tabla con colores cambiados
\global\def\GLOBALtwoside {false}                 % Indica que el documento es twoside

% Definición de formato de secciones
\global\def\GLOBALformatnumchapter {\formatnumchapter}
\global\def\GLOBALformatnumsection {\formatnumsection}
\global\def\GLOBALformatnumssection {\formatnumssection}
\global\def\GLOBALformatnumsssection {\formatnumsssection}
\global\def\GLOBALformatnumssssection {\formatnumssssection}

% Configura si el documento es twoside
\makeatletter
\if@twoside
\global\def\GLOBALtwoside {true}
\else
\fi 
\makeatother

% Signo porcentaje para archivos
\def\LOCALpercentchar#1{}
\edef\LOCALpercentchar{\expandafter\LOCALpercentchar\string\%}

% Contador global de objetos
\newcounter{templateEquations}      % Ecuaciones
\newcounter{templateFigures}        % Figuras
\newcounter{templateIndexEquations} % Ecuaciones en el índice
\newcounter{templateListings}       % Códigos fuente
\newcounter{templatePageCounter}    % Administra números de páginas
\newcounter{templateTables}         % Tablas

% Contador nivel de bookmarks marcadores
\newcounter{templateBookmarksLevelPrev}
\setcounter{templateBookmarksLevelPrev}{\cfgbookmarksopenlevel}
\addtocounter{templateBookmarksLevelPrev}{-1}

% Aumenta contador de páginas
\stepcounter{templatePageCounter}
\AtBeginShipout{\stepcounter{templatePageCounter}}

% Para la compatibilidad con template-tesis se define el capítulo
\newcounter{chapter}

% Define latex para uso en referencias
\let\latex\LaTeX

% Nuevas dimensiones
\newlength{\coregluevarcm}
\setlength{\coregluevarcm}{0.25 cm}
\newlength{\corefontwidth}
\settowidth{\corefontwidth}{template}

% Lanza un mensaje de error
% 	#1	Función del error
%	#2	Mensaje
\newcommand{\throwerror}[2]{%
	\errmessage{LaTeX Error: \noexpand#1 #2 (linea \the\inputlineno)}%
	\stop
}

% Lanza un mensaje de advertencia
%	#1	Mensaje
\newcommand{\throwwarning}[1]{%
	\errmessage{LaTeX Warning: #1 (linea \the\inputlineno)}%
}

% Lanza un mensaje de error indicando mala configuración dentro de begin{document}
%	#1	Mensaje de error
% 	#2	Configuración usada
%	#3	Valores esperados
\newcommand{\throwbadconfigondoc}[3]{%
	\errmessage{#1 \noexpand #2=#2. Valores esperados: #3}%
	\stop%
}

% Comprueba si una variable está definida
%	#1	Variable
\newcommand{\checkvardefined}[1]{%
	\ifthenelse{\isundefined{#1}}{%
		\errmessage{LaTeX Warning: Variable \noexpand#1 no definida}%
		\stop}{%
	}%
}

% Escribe un mensaje en la consola
%	#1	Mensaje
\newcommand{\coretemplatemessage}[1]{%
	\message{Template: #1}%
}

% Comprueba si una variable está definida
%	#1	Variable
%	#2	Mensaje
\newcommand{\checkextravarexist}[2]{%
	\ifthenelse{\isundefined{#1}}{%
		\errmessage{LaTeX Warning: Variable \noexpand#1 no definida}%
		\ifx\hfuzz#2\hfuzz%
			\errmessage{LaTeX Warning: Defina la variable en el bloque de INFORMACION DEL DOCUMENTO al comienzo del archivo principal del template}%
		\else%
			\errmessage{LaTeX Warning: #2}%
		\fi}{%
	}%
}

% Lanza un mensaje de error si una variable no ha sido definida
% 	#1	Función del error
%	#2	Variable
%	#3	Mensaje
\newcommand{\emptyvarerr}[3]{%
	\ifx\hfuzz#2\hfuzz%
		\errmessage{LaTeX Warning: \noexpand#1 #3 (linea \the\inputlineno)}%
	\fi
}

% Cambiar el margen de los caption
% 	#1	Margen en centímetros
\newcommand{\setcaptionmargincm}[1]{
	\captionsetup{margin=#1cm}
}

% Cambia márgenes de las páginas [cm]
% 	#1	Margen izquierdo
%	#2	Margen superior
%	#3	Margen derecho
%	#4	Margen inferior
\newcommand{\setpagemargincm}[4]{
	\ifthenelse{\equal{\compilertype}{lualatex}}{
		% Geometry no válido en lualatex
	}{
		\newgeometry{left=#1cm, top=#2cm, right=#3cm, bottom=#4cm}
	}
}

% Define el caption del índice
% 	#1	Título del caption
\newcommand{\setindexcaption}[1]{%
	\global\def\GLOBALcaptiondefn {#1}%
}

% Resetea los caption
\newcommand{\resetindexcaption}{%
	\global\def\GLOBALcaptiondefn {EMPTY-VAR}%
	\hbadness=10000%
}

% Cambia los márgenes del documento
%	#1	Margen izquierdo
%	#2	Margen derecho
\newcommand{\changemargin}[2]{%
	\emptyvarerr{\changemargin}{#1}{Margen izquierdo no definido}%
	\emptyvarerr{\changemargin}{#2}{Margen derecho no definido}%
	\list{}{\rightmargin#2\leftmargin#1}\item[]%
}
\let\endchangemargin=\endlist

% Chequea que las funciones sólo puedan usarse en el entorno images
\newcommand{\checkonlyonenvimage}{%
	\ifthenelse{\equal{\GLOBALenvimageinitialized}{true}}{}{%
		\throwwarning{Funciones \noexpand\addimage o \noexpand\addimageboxed no pueden usarse fuera del entorno \noexpand\images}\stop%
	}%
}

% Chequea que las funciones sólo puedan usarse fuera del entorno images
\newcommand{\checkoutsideenvimage}{%
	\ifthenelse{\equal{\GLOBALenvimageinitialized}{true}}{%
		\throwwarning{Esta funcion solo puede usarse fuera del entorno \noexpand\images}%
		\stop}{%
	}%
}

% Chequea que las funciones puedan usarse solo en el entorno multicol
\newcommand{\checkinsidemulticol}{%
	\ifthenelse{\equal{\GLOBALenvmulticol}{false}}{%
		\throwwarning{Esta funcion solo puede usarse dentro de multicols}%
		\stop}{%
	}%
}

% Chequea que las funciones puedan usarse fuera del entorno anexo
\newcommand{\checkoutsideappendix}{%
	\ifthenelse{\equal{\GLOBALenvappendix}{true}}{%
		\throwwarning{Esta funcion solo puede usarse fuera de anexo}%
		\stop}{%
	}%
}

% Verifica que una variable sea del estilo "true" o "false"
\newcommand{\corecheckbooleanvar}[1]{%
	\emptyvarerr{\corecheckbooleanvar}{#1}{Variable no definida}%
	\ifthenelse{\equal{#1}{true}}{}{%
	\ifthenelse{\equal{#1}{false}}{}{%
		\throwwarning{Variable debe ser true o false}\stop%
	}}%
}

% Centra verticalmente un texto
%	#1	Texto a centrar
\newcommand{\verticallycentertext}[1]{%
	\emptyvarerr{\verticallycentertext}{#1}{Texto no definido}%
	\topskip0pt%
	\vspace*{\fill}%
	#1%
	\vspace*{\fill}%
}

% Inserta un espacio vertical en cm con una variación +/-
%	#1	Espacio (en cm)
\newcommand{\corevspacevarcm}[1]{%
	\ifthenelse{\equal{#1}{0}}{}{%
	\ifthenelse{\equal{#1}{0.0}}{}{%
		\vspace{\dimexpr#1 cm plus #1\coregluevarcm minus #1\coregluevarcm}%
	}}%
}

% Agrega una carpeta al path de imágenes
%	#1	Carpeta
\makeatletter
\newcommand\addpathimage[1]{%
	\gappto\Ginput@path{{#1}}%
}
\makeatother

% Verifica que un tamaño de fuente sea correcto
%	#1	Tamaño de fuente
\newcommand{\corecheckfontsize}[1]{%
	\ifthenelse{\equal{#1}{normalsize}}{}{%
	\ifthenelse{\equal{#1}{small}}{}{%
	\ifthenelse{\equal{#1}{large}}{}{%
	\ifthenelse{\equal{#1}{Large}}{}{%
	\ifthenelse{\equal{#1}{LARGE}}{}{%
	\ifthenelse{\equal{#1}{huge}}{}{%
	\ifthenelse{\equal{#1}{Huge}}{}{%
	\ifthenelse{\equal{#1}{HUGE}}{}{%
	\ifthenelse{\equal{#1}{footnotesize}}{}{%
	\ifthenelse{\equal{#1}{scriptsize}}{}{%
	\ifthenelse{\equal{#1}{tiny}}{}{%
		\errmessage{LaTeX Warning: Tamano de fuente incorrecto (\noexpand #1= #1). Valores esperados: tiny,scriptsize,footnotesize,small,normalisize,large,Large,LARGE,huge,Huge,HUGE}%
		\stop%
		}}}}}}}}}}%
	}%
}

% Insertar sub-índice, a_b
% 	#1	Elemento inferior (a)
%	#2	Elemento superior (b)
\newcommand{\lpow}[2]{%
	\ensuremath{{#1}_{#2}}
}

% Insertar elevado, a^b
% 	#1	Elemento inferior (a)
%	#2	Elemento superior (b)
\newcommand{\pow}[2]{%
	\ensuremath{{#1}^{#2}}
}

% Inserta inverso función seno, sin^-1
%	#1	Elemento
\newcommand{\aasin}[1][]{%
	\ifx\hfuzz#1\hfuzz%
		\ensuremath{\sin^{-1}#1}
	\else%
		\ensuremath{{\sin}^{-1}}
	\fi%
}

% Inserta inverso función coseno, cos^-1
%	#1	Elemento
\newcommand{\aacos}[1][]{%
	\ifx\hfuzz#1\hfuzz%
		\ensuremath{\cos^{-1}#1}
	\else%
		\ensuremath{\cos^{-1}}
	\fi%
}

% Inserta inverso función tangente, tan^-1
%	#1	Elemento
\newcommand{\aatan}[1][]{%
	\ifx\hfuzz#1\hfuzz%
		\ensuremath{\tan^{-1}#1}
	\else%
		\ensuremath{\tan^{-1}}
	\fi%
}

% Inserta inverso función cosecante, csc^-1
%	#1	Elemento
\newcommand{\aacsc}[1][]{%
	\ifx\hfuzz#1\hfuzz%
		\ensuremath{\csc^{-1}#1}
	\else%
		\ensuremath{\csc^{-1}}
	\fi%
}

% Inserta inverso función secante, sec^-1
%	#1	Elemento
\newcommand{\aasec}[1][]{%
	\ifx\hfuzz#1\hfuzz%
		\ensuremath{\sec^{-1}#1}
	\else%
		\ensuremath{\sec^{-1}}
	\fi%
}

% Inserta inverso función cotangente, cot^-1
%	#1	Elemento
\newcommand{\aacot}[1][]{%
	\ifx\hfuzz#1\hfuzz%
		\ensuremath{\cot^{-1}#1}
	\else%
		\ensuremath{\cot^{-1}}
	\fi%
}

% Fracción de derivadas parciales af/ax
% 	#1	Función a derivar (f)
%	#2	Variable a derivar (x)
\newcommand{\fracpartial}[2]{%
	\ensuremath{\pdv{#1}{#2}}
}

% Fracción de derivadas parciales dobles a^2f/ax^2
% 	#1	Función a derivar (f)
%	#2	Variable a derivar (x)
\newcommand{\fracdpartial}[2]{%
	\ensuremath{\pdv[2]{#1}{#2}}
}

% Fracción de derivadas parciales en n, a^nf/ax^n
% 	#1	Función a derivar (f)
%	#2	Variable a derivar (x)
%	#3	Orden (n)
\newcommand{\fracnpartial}[3]{%
	\ensuremath{\pdv[#3]{#1}{#2}}
}

% Fracción de derivadas df/dx
% 	#1	Función a derivar (f)
%	#2	Variable a derivar (x)
\newcommand{\fracderivat}[2]{%
	\ensuremath{\dv{#1}{#2}}
}

% Fracción de derivadas dobles d^2/dx^2
% 	#1	Función a derivar (f)
%	#2	Variable a derivar (x)
\newcommand{\fracdderivat}[2]{%
	\ensuremath{\dv[2]{#1}{#2}}
}

% Fracción de derivadas en n d^nf/dx^n
% 	#1	Función a derivar (f)
%	#2	Variable a derivar (x)
%	#3	Orden de la derivada (n)
\newcommand{\fracnderivat}[3]{%
	\ensuremath{\dv[#3]{#1}{#2}}
}

% Llave superior de equivalencia
% 	#1	Elemento a igualar
%	#2	Igualdad
\newcommand{\topequal}[2]{%
	\ensuremath{\overbrace{#1}^{\mathclap{#2}}}
}
\newcommand{\topequaltext}[2]{%
	\topequal{#1}{\text{#2}}
}

% Llave inferior de equivalencia
% 	#1	Elemento a igualar
%	#2	Igualdad
\newcommand{\underequal}[2]{%
	\ensuremath{\underbrace{#1}_{\mathclap{#2}}}
}
\newcommand{\underequaltext}[2]{%
	\underequal{#1}{\text{#2}}
}

% Rectángulo superior de equivalencia
% 	#1	Elemento a igualar
%	#2	Igualdad
\newcommand{\topsequal}[2]{%
	\ensuremath{\overbracket{#1}^{\mathclap{#2}}}
}
\newcommand{\topsequaltext}[2]{%
	\topsequal{#1}{\text{#2}}
}

% Rectángulo inferior de equivalencia
% 	#1	Elemento a igualar
%	#2	Igualdad
\newcommand{\undersequal}[2]{%
	\ensuremath{\underbracket{#1}_{\mathclap{#2}}}
}
\newcommand{\undersequaltext}[2]{%
	\undersequal{#1}{\text{#2}}
}

% Función piso
% 	#1	Elemento
\newcommand{\floorexp}[1]{%
	\ensuremath{\left\lfloor{#1}\right\rfloor}
}

% Función techo
% 	#1	Elemento
\newcommand{\ceilexp}[1]{%
	\ensuremath{\left\lceil{#1}\right\rceil}
}

% Función mod
%	#1	Elemento tal que (mod #1)
\newcommand{\Mod}[1]{%
	\ensuremath{\ (\mathrm{mod}\ #1)}
}

% Paréntesis grande
% 	#1	Expresión
\newcommand{\bigp}[1]{%
	\ensuremath{\big(#1\big)}
}

% Paréntesis g+grande
% 	#1	Expresión
\newcommand{\biggp}[1]{%
	\ensuremath{\bigg(#1\bigg)}
}

% Cajón grande
% 	#1	Expresión
\newcommand{\bigc}[1]{%
	\ensuremath{\big[#1\big]}
}

% Cajón g+grande
% 	#1	Expresión
\newcommand{\biggc}[1]{%
	\ensuremath{\bigg[#1\bigg]}
}

% Llave grande
% 	#1	Expresión
\newcommand{\bigb}[1]{%
	\ensuremath{\big\{#1\big\}}
}

% Llave g+grande
% 	#1	Expresión
\newcommand{\biggb}[1]{%
	\ensuremath{\bigg\{#1\bigg\}}
}

% Expresión divergencia
\newcommand{\divexp}{%
	\ensuremath{\rm{div}\ }
}

% Expresión automorfismo
\newcommand{\Autexp}{%
	\ensuremath{\rm{Aut}}
}

% Negrita introducida por word
% 	#1	Expresión
\newcommand{\mathbit}[1]{%
	\bm{#1}
}

% Expresión diff
\newcommand{\Diffexp}{%
	\ensuremath{\rm{Diff}}
}

% Expresión imaginario
\newcommand{\Imexp}{%
	\ensuremath{\rm{Im}}
}

% Expresión imaginario en z
\newcommand{\Imzexp}{%
	\ensuremath{\rm{Im}(z)}
}

% Expresión real
\newcommand{\Reexp}{%
	\ensuremath{\rm{Re}}
}

% Expresión real en z
\newcommand{\Rezexp}{%
	\ensuremath{\rm{Re}(z)}
}

% Barra superior en elemento
%	#1 	Elemento
\newcommand{\overbar}[1]{%
	\mkern 1.5mu\overline{\mkern-1.5mu#1\mkern-1.5mu}\mkern 1.5mu
}

% Función \tilde{} pero que encierra todo el texto
%	#1 	Elemento
\makeatletter
\def\longtilde#1{%
	\mathop{\vbox{\m@th\ialign{##\crcr\noalign{\kern3\p@}%
	\sortoftildefill\crcr\noalign{\kern3\p@\nointerlineskip}%
	$\hfil\displaystyle{#1}\hfil$\crcr}}}\limits%
}
\def\sortoftildefill {%
	$\m@th \setbox\z@\hbox{$\braceld$}%
	\braceld\leaders\vrule \@height\ht\z@ \@depth\z@\hfill\braceru$%
}
\makeatother

% Definición de letras
\newcommand{\A}{\ensuremath{\mathcal{A}}}

\newcommand{\B}{\ensuremath{\mathcal{B}}}

\ifthenelse{\isundefined{\C}}{\newcommand{\C}{C}}{\let\oldC=\C}
\renewcommand{\C}{\ensuremath{\mathbb{C}}}

\newcommand{\D}{\ensuremath{\mathbb{D}}}

\newcommand{\E}{\ensuremath{\mathbb{E}}}

\newcommand{\F}{\ensuremath{\mathcal{F}}}

\ifthenelse{\isundefined{\G}}{\newcommand{\G}{G}}{\let\oldG=\G}
\renewcommand{\G}{\ensuremath{\mathcal{G}}}

\ifthenelse{\isundefined{\H}}{\newcommand{\H}{H}}{\let\oldH=\H}
\renewcommand{\H}{\ensuremath{\mathcal{H}}}

\newcommand{\I}{\ensuremath{\mathbb{I}}}

\newcommand{\J}{\ensuremath{\mathcal{J}}}

\newcommand{\K}{\ensuremath{\mathcal{K}}}

\let\oldL=\L % L con una raya
\renewcommand{\L}{\ensuremath{\mathcal{L}}}

\newcommand{\M}{\ensuremath{\mathcal{M}}}

\newcommand{\N}{\ensuremath{\mathbb{N}}}

% \renewcommand{\O}{\ensuremath{\mathbb{O}}} % O equivale a o/oo

\let\oldP=\P % P negra
\renewcommand{\P}{\ensuremath{\mathbb{P}}}

\newcommand{\Q}{\ensuremath{\mathbb{Q}}}

\newcommand{\R}{\ensuremath{\mathbb{R}}}

\let\oldS=\S % Serpiente
\renewcommand{\S}{\ensuremath{\mathcal{S}}}

\newcommand{\T}{\ensuremath{\mathcal{T}}}

\ifthenelse{\isundefined{\U}}{\newcommand{\U}{U}}{\let\oldU=\U}
\renewcommand{\U}{\ensuremath{\mathcal{U}}}

\newcommand{\V}{\ensuremath{\mathcal{V}}}

\newcommand{\W}{\ensuremath{\mathcal{W}}}

\newcommand{\X}{\ensuremath{\mathcal{X}}}

\newcommand{\Y}{\ensuremath{\mathcal{Y}}}

\newcommand{\Z}{\ensuremath{\mathbb{Z}}}

% Definición de operadores matemáticos de asignación (Typeset assigments)
\ifthenelse{\equal{\fontdocument}{step}}{}{ % Ya definidos en STEP
	\newcommand{\asteq}{\ensuremath{\mathrel{{*}{=}}}}
	\newcommand{\eqeq}{\ensuremath{\mathrel{{=}{=}}}}
}
\newcommand{\cdoteq}{\ensuremath{\mathrel{{\cdot}{=}}}}
\newcommand{\diveq}{\ensuremath{\mathrel{{/}{=}}}}
\newcommand{\eqast}{\ensuremath{\mathrel{{=}{*}}}}
\newcommand{\eqcdot}{\ensuremath{\mathrel{{=}{\cdot}}}}
\newcommand{\eqdiv}{\ensuremath{\mathrel{{=}{/}}}}
\newcommand{\eqminus}{\ensuremath{\mathrel{{=}{-}}}}
\newcommand{\eqnot}{\ensuremath{\mathrel{{=}{!}}}}
\newcommand{\eqplus}{\ensuremath{\mathrel{{=}{+}}}}
\newcommand{\eqtimes}{\ensuremath{\mathrel{{=}{\times}}}}
\newcommand{\minuseq}{\ensuremath{\mathrel{{-}{=}}}}
\newcommand{\minusminus}{\ensuremath{\mathrel{{-}{-}}}}
\newcommand{\noteq}{\ensuremath{\mathrel{{!}{=}}}}
\newcommand{\pluseq}{\ensuremath{\mathrel{{+}{=}}}}
\newcommand{\plusplus}{\ensuremath{\mathrel{{+}{+}}}}
\newcommand{\timeseq}{\ensuremath{\mathrel{{\times}{=}}}}

% Definición de teoremas y lemas
\makeatletter
	\renewenvironment{proof}[1][\proofname]{%
		\par\pushQED{\qed}%
		\normalfont\topsep6\p@\@plus6\p@\relax\trivlist%
		\item[\hskip\labelsep\scshape\footnotesize#1\@addpunct{.}]%
		\ignorespaces%
	}{%
		\popQED\endtrivlist\@endpefalse%
	}%
\makeatother

% Función que se ejecuta tras un equation
\newcommand{\coreafterequationfn}{%
	\hbadness=10000%
}

% Redimensiona una ecuación en linewidth
% 	#1	Tamaño del nuevo objeto (En linewidth)
%	#2	Ecuación a redimensionar
\newcommand{\equationresize}[2]{%
	\emptyvarerr{\equationresize}{#1}{Dimension no definida}%
	\emptyvarerr{\equationresize}{#2}{Ecuacion a redimensionar no definida}%
	\resizebox{#1\linewidth}{!}{$#2$}%
}

% Inserta el caption de un objeto tipo ecuación
%	#1	Texto del caption
\newcommand{\coreinsertequationcaption}[1]{%
	\begin{changemargin}{\captionlrmargin cm}{\captionlrmargin cm}%
		\ifthenelse{\equal{\equationcaptioncenter}{true}}{%
			\centering%
		}{%
			\justifying%
		}%
		\textcolor{\captiontextcolor}{%
			\linespread{0.5}\selectfont{%
				\begin{\captionfontsize}#1\end{\captionfontsize}%
			}%
		}%
	\end{changemargin}
}

% Insertar una ecuación
% 	#1	Label (opcional)
%	#2	Ecuación
\newcommand{\insertequation}[2][]{%
	\emptyvarerr{\insertequation}{#2}{Ecuacion no definida}%
	\ifthenelse{\equal{\numberedequation}{true}}{%
		\corevspacevarcm{\marginequationtop}%
		\begin{samepage}%
		\begin{equation}%
			\text{#1} #2
		\end{equation}
		\corevspacevarcm{\marginequationbottom}%
		\end{samepage}
		\coreafterequationfn%
	}{%
		\ifx\hfuzz#1\hfuzz%
		\else%
			\throwwarning{Label invalido en ecuacion sin numero}%
		\fi%
		\insertequationanum{#2}%
	}%
}

% Insertar una ecuación sin número
%	#1	Ecuación
\newcommand{\insertequationanum}[1]{%
	\emptyvarerr{\insertequationanum}{#1}{Ecuacion no definida}%
	\corevspacevarcm{\marginequationtop}%
	\begin{samepage}%
	\begin{equation*}%
		\ensuremath{#1}
	\end{equation*}
	\corevspacevarcm{\marginequationbottom}%
	\end{samepage}
	\coreafterequationfn%
}

% Insertar una ecuación alineada a la izquierda
% 	#1	Label (opcional)
%	#2	Ecuación
\newcommand{\insertequationleft}[2][]{%
	\emptyvarerr{\insertequationleft}{#2}{Ecuacion no definida}%
	\ifthenelse{\equal{\numberedequation}{true}}{%
		\vspace{\dimexpr\marginequationtop cm - \baselineskip}%
		\begin{samepage}%
		\begin{equation}
			\hfilneg \text{#1} #2 \hspace{10000pt minus 1fil}
		\end{equation}
		\vspace{\dimexpr-0.2\baselineskip + \marginequationbottom cm}%
		\end{samepage}
		\coreafterequationfn%
	}{%
		\ifx\hfuzz#1\hfuzz%
		\else%
			\throwwarning{Label invalido en ecuacion sin numero}%
		\fi%
		\insertequationleftanum{#2}%
	}%
}

% Insertar una ecuación sin número alineada a la izquierda
%	#1	Ecuación
\newcommand{\insertequationleftanum}[1]{%
	\emptyvarerr{\insertequationleftanum}{#1}{Ecuacion no definida}%
	\vspace{\dimexpr\marginequationtop cm - \baselineskip}%
	\begin{samepage}%
	\begin{equation*}
		\hfilneg \ensuremath{#1} \hspace{10000pt minus 1fil}
	\end{equation*}
	\vspace{\dimexpr-0.2\baselineskip + \marginequationbottom cm}%
	\end{samepage}
	\coreafterequationfn%
}

% Insertar una ecuación alineada a la derecha
% 	#1	Label (opcional)
%	#2	Ecuación
\newcommand{\insertequationright}[2][]{%
	\emptyvarerr{\insertequationright}{#2}{Ecuacion no definida}%
	\ifthenelse{\equal{\numberedequation}{true}}{%
		\vspace{\dimexpr\marginequationtop cm - \baselineskip}%
		\begin{samepage}%
		\begin{equation}
			\hspace{10000pt minus 1fil} \text{#1} #2 \hfilneg
		\end{equation}
		\vspace{\dimexpr-0.2\baselineskip + \marginequationbottom cm}%
		\end{samepage}
		\coreafterequationfn%
	}{%
		\ifx\hfuzz#1\hfuzz%
		\else%
			\throwwarning{Label invalido en ecuacion sin numero}%
		\fi%
		\insertequationrightanum{#2}%
	}%
}

% Insertar una ecuación sin número alineada a la derecha
%	#1	Ecuación
\newcommand{\insertequationrightanum}[1]{%
	\emptyvarerr{\insertequationrightanum}{#1}{Ecuacion no definida}%
	\vspace{\dimexpr\marginequationtop cm - \baselineskip}%
	\begin{samepage}%
	\begin{equation*}
		\hspace{10000pt minus 1fil} \ensuremath{#1} \hfilneg
	\end{equation*}
	\vspace{\dimexpr-0.2\baselineskip + \marginequationbottom cm}%
	\end{samepage}
	\coreafterequationfn%
}

% Insertar una ecuación con leyenda
% 	#1	Label (opcional)
%	#2	Ecuación
%	#3	Leyenda
\newcommand{\insertequationcaptioned}[3][]{%
	\emptyvarerr{\insertequationcaptioned}{#2}{Ecuacion no definida}%
	\ifx\hfuzz#3\hfuzz%
		\insertequation[#1]{#2}%
	\else%
		\ifthenelse{\equal{\numberedequation}{true}}{%
			\corevspacevarcm{\marginequationtop}%
			\begin{samepage}%
			\begin{equation}
				\text{#1} #2
			\end{equation}
			\corevspacevarcm{\margineqncaptiontop}%
			\coreinsertequationcaption{#3}%
			\corevspacevarcm{\margineqncaptionbottom}%
			\end{samepage}
			\coreafterequationfn%
		}{%
			\ifx\hfuzz#1\hfuzz%
			\else%
				\throwwarning{Label invalido en ecuacion sin numero}%
			\fi%
			\insertequationcaptionedanum{#2}{#3}%
		}%
	\fi%
}

% Insertar una ecuación con leyenda sin número
%	#1	Ecuación
%	#2	Leyenda
\newcommand{\insertequationcaptionedanum}[2]{%
	\emptyvarerr{\insertequationcaptionedanum}{#1}{Ecuacion no definida}%
	\ifx\hfuzz#2\hfuzz%
		\insertequationanum{#1}%
	\else%
		\corevspacevarcm{\marginequationtop}%
		\begin{samepage}%
		\begin{equation*}
			\ensuremath{#1}%
		\end{equation*}
		\corevspacevarcm{\margineqncaptiontop}%
		\coreinsertequationcaption{#2}%
		\corevspacevarcm{\margineqncaptionbottom}%
		\end{samepage}
		\coreafterequationfn%
	\fi%
}

% Insertar una ecuación con el ambiente gather
%	#1	Ecuación
\newcommand{\insertgather}[1]{%
	\emptyvarerr{\insertgather}{#1}{Ecuacion no definida}%
	\ifthenelse{\equal{\numberedequation}{true}}{%
		\corevspacevarcm{\margingathertop}%
		\begin{samepage}%
		\begin{gather}%
			\ensuremath{#1}
		\end{gather}
		\corevspacevarcm{\margingatherbottom}%
		\end{samepage}
		\coreafterequationfn%
	}{%
		\insertgatheranum{#1}%
	}%
}

% Insertar una ecuación con el ambiente gather sin número
%	#1	Ecuación
\newcommand{\insertgatheranum}[1]{%
	\emptyvarerr{\insertgatheranum}{#1}{Ecuacion no definida}%
	\corevspacevarcm{\margingathertop}%
	\begin{samepage}%
	\begin{gather*}%
		\ensuremath{#1}
	\end{gather*}
	\corevspacevarcm{\margingatherbottom}%
	\end{samepage}
	\coreafterequationfn%
}

% Insertar una ecuación (gather) con leyenda
%	#1	Ecuación
%	#2	Leyenda
\newcommand{\insertgathercaptioned}[2]{%
	\emptyvarerr{\insertgathercaptioned}{#1}{Ecuacion no definida}%
	\ifx\hfuzz#2\hfuzz%
		\insertgather{#1}%
	\else%
		\ifthenelse{\equal{\numberedequation}{true}}{%
			\corevspacevarcm{\margingathertop}%
			\begin{samepage}%
			\begin{gather}%
				\ensuremath{#1}
			\end{gather}
			\corevspacevarcm{\margingathercapttop}%
			\coreinsertequationcaption{#2}%
			\corevspacevarcm{\margingathercaptbottom}%
			\end{samepage}
			\coreafterequationfn%
		}{%
			\insertgathercaptionedanum{#1}{#2}%
		}%
	\fi%
}

% Insertar una ecuación (gather) con leyenda sin número
%	#1	Ecuación
%	#2	Leyenda
\newcommand{\insertgathercaptionedanum}[2]{%
	\emptyvarerr{\insertgathercaptionedanum}{#1}{Ecuacion no definida}%
	\ifx\hfuzz#2\hfuzz%
		\insertgatheranum{#1}%
	\else%
		\corevspacevarcm{\margingathertop}%
		\begin{samepage}%
		\begin{gather*}%
			\ensuremath{#1}
		\end{gather*}
		\corevspacevarcm{\margingathercapttop}%
		\coreinsertequationcaption{#2}%
		\corevspacevarcm{\margingathercaptbottom}%
		\end{samepage}
		\coreafterequationfn%
	\fi%
}

% Insertar una ecuación con el ambiente gathered
% 	#1	Label (opcional)
%	#2	Ecuación
\newcommand{\insertgathered}[2][]{%
	\emptyvarerr{\insertgathered}{#2}{Ecuacion no definida}%
	\ifthenelse{\equal{\numberedequation}{true}}{%
		\corevspacevarcm{\marginequationtop}%
		\begin{samepage}%
		\begin{equation}
			\begin{gathered}
				\text{#1} \ensuremath{#2}
			\end{gathered}
		\end{equation}
		\corevspacevarcm{\margingatheredbottom}%
		\end{samepage}
	}{%
		\ifx\hfuzz#1\hfuzz%
		\else%
			\throwwarning{Label invalido en ecuacion (gathered) sin numero}%
		\fi%
		\corevspacevarcm{\margingatheredtop}%
		\begin{samepage}%
		\begin{gather*}%
			\ensuremath{#2}
		\end{gather*}
		\corevspacevarcm{\margingatheredbottom}%
		\end{samepage}
	}%
	\coreafterequationfn%
}

% Insertar una ecuación con el ambiente gathered sin número
%	#1	Ecuación
\newcommand{\insertgatheredanum}[1]{%
	\emptyvarerr{\insertgatheredanum}{#1}{Ecuacion no definida}%
	\corevspacevarcm{\margingatheredtop}%
	\begin{samepage}%
	\begin{gather*}
		\ensuremath{#1}
	\end{gather*}
	\vspace{\dimexpr-0.15cm + \margingatheredbottom cm}%
	\end{samepage}
	\coreafterequationfn%
}

% Insertar una ecuación (gathered) con leyenda
% 	#1	Label (opcional)
%	#2	Ecuación
%	#3	Leyenda
\newcommand{\insertgatheredcaptioned}[3][]{%
	\emptyvarerr{\insertgatheredcaptioned}{#2}{Ecuacion no definida}%
	\ifx\hfuzz#3\hfuzz%
		\insertgathered[#1]{#2}%
	\else%
		\ifthenelse{\equal{\numberedequation}{true}}{%
			\corevspacevarcm{\marginequationtop}%
			\begin{samepage}%
			\begin{equation}
				\begin{gathered}
					\text{#1} \ensuremath{#2}
				\end{gathered}
			\end{equation}
			\corevspacevarcm{\margingatheredcapttop}%
			\coreinsertequationcaption{#3}%
			\corevspacevarcm{\margingatheredcaptbottom}%
			\end{samepage}
			\coreafterequationfn%
		}{%
			\ifx\hfuzz#1\hfuzz%
			\else%
				\throwwarning{Label invalido en ecuacion (gathered) sin numero}
			\fi%
			\insertgatheredcaptionedanum{#2}{#3}%
		}%
	\fi%
}

% Insertar una ecuación (gathered) con leyenda sin número
%	#1	Ecuación
%	#2	Leyenda
\newcommand{\insertgatheredcaptionedanum}[2]{
	\emptyvarerr{\insertgatheredcaptionedanum}{#1}{Ecuacion no definida}
	\ifx\hfuzz#2\hfuzz%
		\insertgatheredanum{#1}%
	\else%
		\corevspacevarcm{\margingatheredtop}%
		\begin{samepage}%
		\begin{gather*}
			\ensuremath{#1}
		\end{gather*}
		\vspace{\dimexpr-0.2cm + \margingatheredcapttop cm}%
		\coreinsertequationcaption{#2}%
		\vspace{\dimexpr-0.05cm + \margingatheredcaptbottom cm}%
		\end{samepage}
		\coreafterequationfn%
	\fi%
}

% Insertar una ecuación con el ambiente align
%	#1	Ecuación
\newcommand{\insertalign}[1]{%
	\emptyvarerr{\insertalign}{#1}{Ecuacion no definida}%
	\ifthenelse{\equal{\numberedequation}{true}}{%
		\corevspacevarcm{\marginaligntop}%
		\begin{samepage}%
		\begin{align}
			\ensuremath{#1}
		\end{align}
		\corevspacevarcm{\marginalignbottom}%
		\end{samepage}
		\coreafterequationfn%
	}{%
		\insertalignanum{#1}%
	}%
}

% Insertar una ecuación con el ambiente align sin número
%	#1	Ecuación
\newcommand{\insertalignanum}[1]{%
	\emptyvarerr{\insertalignanum}{#1}{Ecuacion no definida}%
	\corevspacevarcm{\marginaligntop}%
	\begin{samepage}%
	\begin{align*}
		\ensuremath{#1}
	\end{align*}
	\corevspacevarcm{\marginalignbottom}%
	\end{samepage}
	\coreafterequationfn%
}

% Insertar una ecuación (align) con leyenda
%	#1	Ecuación
%	#2	Leyenda
\newcommand{\insertaligncaptioned}[2]{%
	\emptyvarerr{\insertaligncaptioned}{#1}{Ecuacion no definida}%
	\ifx\hfuzz#2\hfuzz%
		\insertalign{#1}%
	\else%
		\ifthenelse{\equal{\numberedequation}{true}}{%
			\corevspacevarcm{\marginaligntop}%
			\begin{samepage}%
			\begin{align}
				\ensuremath{#1}
			\end{align}
			\corevspacevarcm{\marginaligncapttop}%
			\coreinsertequationcaption{#2}%
			\corevspacevarcm{\marginaligncaptbottom}%
			\end{samepage}
			\coreafterequationfn%
		}{%
			\insertaligncaptionedanum{#1}{#2}%
		}%
	\fi%
}

% Insertar una ecuación (align) con leyenda sin número
%	#1	Ecuación
%	#2	Leyenda
\newcommand{\insertaligncaptionedanum}[2]{%
	\emptyvarerr{\insertaligncaptionedanum}{#1}{Ecuacion no definida}%
	\ifx\hfuzz#2\hfuzz%
		\insertalignanum{#1}%
	\else%
		\corevspacevarcm{\marginaligntop}%
		\begin{samepage}%
		\begin{align*}
			\ensuremath{#1}
		\end{align*}
		\corevspacevarcm{\marginaligncapttop}%
		\coreinsertequationcaption{#2}%
		\corevspacevarcm{\marginaligncaptbottom}%
		\end{samepage}
		\coreafterequationfn%
	\fi%
}

% Insertar una ecuación con el ambiente aligned
% 	#1	Label (opcional)
%	#2	Ecuación
\newcommand{\insertaligned}[2][]{%
	\emptyvarerr{\insertaligned}{#2}{Ecuacion no definida}%
	\ifthenelse{\equal{\numberedequation}{true}}{%
		\corevspacevarcm{\marginequationtop}%
		\begin{samepage}%
		\begin{equation}
			\begin{aligned}
				\text{#1} \ensuremath{#2}
			\end{aligned}
		\end{equation}
		\corevspacevarcm{\marginalignedbottom}%
		\end{samepage}
		\coreafterequationfn%
	}{%
		\ifx\hfuzz#1\hfuzz%
		\else%
			\throwwarning{Label invalido en ecuacion (aligned) sin numero}%
		\fi%
		\insertalignedanum{#2}%
	}%
}

% Insertar una ecuación con el ambiente aligned sin número
%	#1	Ecuación
\newcommand{\insertalignedanum}[1]{%
	\emptyvarerr{\insertalignedanum}{#1}{Ecuacion no definida}%
	\corevspacevarcm{\marginalignedtop}%
	\begin{samepage}%
	\begin{align*}
		\ensuremath{#1}
	\end{align*}
	\vspace{\dimexpr-0.2cm + \marginalignedbottom cm}%
	\end{samepage}
	\coreafterequationfn%
}

% Insertar una ecuación (aligned) con leyenda
% 	#1	Label (opcional)
%	#2	Ecuación
%	#3	Leyenda
\newcommand{\insertalignedcaptioned}[3][]{%
	\emptyvarerr{\insertalignedcaptioned}{#2}{Ecuacion no definida}%
	\ifx\hfuzz#3\hfuzz%
		\insertaligned[#1]{#2}%
	\else%
		\ifthenelse{\equal{\numberedequation}{true}}{%
			\corevspacevarcm{\marginequationtop}%
			\begin{samepage}%
			\begin{equation}
				\begin{aligned}
					\text{#1} \ensuremath{#2}
				\end{aligned}
			\end{equation}
			\corevspacevarcm{\marginalignedcapttop}%
			\coreinsertequationcaption{#3}%
			\corevspacevarcm{\marginalignedcaptbottom}%
			\end{samepage}
			\coreafterequationfn%
		}{%
			\ifx\hfuzz#1\hfuzz%
			\else%
				\throwwarning{Label invalido en ecuacion (aligned) sin numero}%
			\fi%
			\insertalignedcaptionedanum{#2}{#3}%
		}%
	\fi%
}

% Insertar una ecuación (aligned) con leyenda sin número
%	#1	Ecuación
%	#2	Leyenda
\newcommand{\insertalignedcaptionedanum}[2]{%
	\emptyvarerr{\insertalignedcaptionedanum}{#1}{Ecuacion no definida}%
	\ifx\hfuzz#2\hfuzz%
		\insertalignedanum{#1}%
	\else%
		\corevspacevarcm{\marginequationtop}%
		\begin{samepage}%
		\begin{equation}
			\begin{aligned}
				\ensuremath{#1}
			\end{aligned}
		\end{equation}
		\corevspacevarcm{\marginalignedcapttop}%
		\coreinsertequationcaption{#2}%
		\corevspacevarcm{\marginalignedcaptbottom}%
		\end{samepage}
		\coreafterequationfn%
	\fi%
}

\global\def\GLOBALimagelink {} % Almacena el link de la imagen

% Calcula largo hspace
% Regresión entre 35,46446->9 y 52,68402->13,5
\newlength{\coreimageshspace}
\setlength{\coreimageshspace}{\dimexpr 9pt + 0.261330719\corefontwidth - 9.26795284pt}

% Añade una imagen a un env "image" con borde
% 	#1	Label (opcional)
%	#2	Dirección de la imagen
%	#3	Parámetros de la imagen
%	#4	Leyenda de la imagen (opcional)
\newcommand{\addimage}[4][]{%
	\addimageboxed[#1]{#2}{#3}{0}{#4}%
}

% Añade una imagen a un env "image" con borde
% 	#1	Label (opcional)
%	#2	Dirección de la imagen
%	#3	Parámetros de la imagen
%	#4	Ancho de la línea (en pt)
%	#5	Leyenda de la imagen (opcional)
\newcommand{\addimageboxed}[5][]{%
	\checkonlyonenvimage%
	\begingroup%
	\setlength{\fboxsep}{0 pt}%
	\setlength{\fboxrule}{#4 pt}%
	\ifthenelse{\equal{\GLOBALenvimageadded}{true}}{%
		\hspace{\dimexpr \marginimagemultright cm -\coreimageshspace}%
	}{}%
	\ifthenelse{\equal{#5}{}}{ % Sin label
		\ifthenelse{\equal{\GLOBALimagelink}{}}{ % Sin link
			\fbox{}%
		}{ % Con link
			\fbox{\href{\GLOBALimagelink}{}}%
		}%
	}{ % Con label
		\ifthenelse{\equal{\GLOBALimagelink}{}}{ % Sin link
			\subfloat[#5]{%
				\fbox{}#1%
			}%
		}{ % Con link
			\subfloat[#5]{%
				\fbox{\href{\GLOBALimagelink}{}#1}%
			}%
		}%
	}%
	\endgroup%
	\global\def\GLOBALenvimageadded {true}%
}

% Añade una imagen a un env "image" con borde sin leyenda
%	#1	Dirección de la imagen
%	#2	Parámetros de la imagen
\newcommand{\addimageanum}[2]{%
	\addimageboxed{#1}{#2}{0}{}%
}

% Añade una imagen a un env "image" con borde sin leyenda
%	#1	Dirección de la imagen
%	#2	Parámetros de la imagen
%	#3	Ancho de la línea (en pt)
\newcommand{\addimageanumboxed}[3]{%
	\addimageboxed{#1}{#2}{#3}{}%
}

% Añade una imagen a un env "image" con borde animada
% 	#1	Label (opcional)
%	#2	Dirección de la imagen animada
%	#3	Parámetros de la imagen
%	#4	FPS de la imagen
%	#5	Total imágenes no definido
%	#6	Leyenda de la imagen (opcional)
\newcommand{\addimageanimated}[6][]{%
	\addimageanimatedboxed[#1]{#2}{#3}{#4}{#5}{0}{#6}%
}

% Añade una imagen a un env "image" con borde animada
% 	#1	Label (opcional)
%	#2	Dirección de la imagen animada
%	#3	Parámetros de la imagen
%	#4	FPS de la imagen
%	#5	Total imágenes no definido
%	#6	Ancho de la línea (en pt)
%	#7	Leyenda de la imagen (opcional)
\newcommand{\addimageanimatedboxed}[7][]{%
	\checkonlyonenvimage%
	\begingroup%
	\setlength{\fboxsep}{0 pt}%
	\setlength{\fboxrule}{#6 pt}%
	\ifthenelse{\equal{\GLOBALenvimageadded}{true}}{%
		\hspace{\dimexpr \marginimagemultright cm -\coreimageshspace}%
	}{}%
	\ifthenelse{\equal{#7}{}}{ % Sin label
		\ifthenelse{\equal{\animatedimageloop}{true}}{ % Con loop
			\ifthenelse{\equal{\animatedimageautoplay}{true}}{ % Con autoplay
				\fbox{\animategraphics[loop,autoplay,#3]{#4}{#2-}{0}{#5}}%
			}{ % Sin autoplay
				\fbox{\animategraphics[loop,#3]{#4}{#2-}{0}{#5}}%
			}%
		}{ % Sin loop
			\ifthenelse{\equal{\animatedimageautoplay}{true}}{ % Con autoplay
				\fbox{\animategraphics[autoplay,#3]{#4}{#2-}{0}{#5}}%
			}{ % Sin autoplay
				\fbox{\animategraphics[#3]{#4}{#2-}{0}{#5}}%
			}%
		}%
	}{ % Con label
		\subfloat[#7]{%
			\ifthenelse{\equal{\animatedimageloop}{true}}{ % Con loop
				\ifthenelse{\equal{\animatedimageautoplay}{true}}{ % Con autoplay
					\fbox{\animategraphics[loop,autoplay,#3]{#4}{#2-}{0}{#5}#1}%
				}{ % Sin autoplay
					\fbox{\animategraphics[loop,#3]{#4}{#2-}{0}{#5}#1}%
				}%
			}{ % Sin loop
				\ifthenelse{\equal{\animatedimageautoplay}{true}}{ % Con autoplay
					\fbox{\animategraphics[autoplay,#3]{#4}{#2-}{0}{#5}#1}%
				}{ % Sin autoplay
					\fbox{\animategraphics[#3]{#4}{#2-}{0}{#5}#1}%
				}%
			}%
		}%
	}%
	\endgroup%
	\global\def\GLOBALenvimageadded {true}%
}

% Añade una imagen a un env "image" con borde sin leyenda animada
%	#1	Dirección de la imagen animada
%	#2	Parámetros de la imagen
%	#3	FPS de la imagen
%	#4	Total imágenes no definido
\newcommand{\addimageanimatedanum}[4]{%
	\addimageanimatedboxed{#1}{#2}{#3}{#4}{0}{}%
}

% Añade una imagen a un env "image" con borde sin leyenda animada
%	#1	Dirección de la imagen animada
%	#2	Parámetros de la imagen
%	#3	FPS de la imagen
%	#4	Total imágenes no definido
%	#5	Ancho de la línea (en pt)
\newcommand{\addimageanimatedanumboxed}[5]{%
	\addimageanimatedboxed{#1}{#2}{#3}{#4}{#5}{}%
}

% Añade una imagen a un env "image" con borde y un link
% 	#1	Label (opcional)
%	#2	Dirección de la imagen
%	#3	Parámetros de la imagen
%	#4	Link de la imagen
%	#5	Leyenda de la imagen (opcional)
\newcommand{\addimagelink}[5][]{%
	\addimagelinkboxed[#1]{#2}{#3}{0}{#4}{#5}%
}

% Añade una imagen a un env "image" con borde
% 	#1	Label (opcional)
%	#2	Dirección de la imagen
%	#3	Parámetros de la imagen
%	#4	Ancho de la línea (en pt)
%	#5	Link de la imagen
%	#6	Leyenda de la imagen (opcional)
\newcommand{\addimagelinkboxed}[6][]{%
	\global\def\GLOBALimagelink {#5}%
	\addimageboxed[#1]{#2}{#3}{#4}{#6}%
	\global\def\GLOBALimagelink {}%
}

% Añade una imagen a un env "image" con borde sin leyenda
%	#1	Dirección de la imagen
%	#2	Parámetros de la imagen
%	#3	Link de la imagen
\newcommand{\addimageanumlink}[3]{%
	\addimagelink{#1}{#2}{#3}{}%
}

% Añade una imagen a un env "image" con borde sin leyenda
%	#1	Dirección de la imagen
%	#2	Parámetros de la imagen
%	#3	Ancho de la línea (en pt)
%	#4	Link de la imagen
\newcommand{\addimageanumlinkboxed}[4]{%
	\addimagelinkboxed{#1}{#2}{#3}{#4}{}%
}

% Añade un salto de línea en las imágenes
\newcommand{\imagesnewline}{%
	\checkonlyonenvimage%
	\global\def\GLOBALenvimageadded {false}%
	\corevspacevarcm{\marginimagemultbottom}%
	~\linebreak\noindent%
}

% Agrega un espacio horizontal a las imágenes
% 	#1 Tamaño del espacio
\newcommand{\imageshspace}[1]{%
	\checkonlyonenvimage%
	\global\def\GLOBALenvimageadded {false}%
	\hspace{#1}%
}

% Agrega un espacio vertical a las imágenes
% 	#1 Tamaño del espacio
\newcommand{\imagesvspace}[1]{%
	\checkonlyonenvimage%
	\global\def\GLOBALenvimageadded {false}%
	~ \\ \vspace*{#1}%
}

% Insertar una imagen
% 	#1	Label (opcional)
%	#2	Dirección de la imagen
%	#3	Parámetros de la imagen
%	#4	Leyenda de la imagen (opcional)
\newcommand{\insertimage}[4][]{%
	\insertimageboxed[#1]{#2}{#3}{0}{#4}%
}

% Insertar una imagen con recuadro
% 	#1	Label (opcional)
%	#2	Dirección de la imagen
%	#3	Parámetros de la imagen
%	#4	Ancho de la línea (en pt)
%	#5	Leyenda de la imagen (opcional)
\newcommand{\insertimageboxed}[5][]{%
	\emptyvarerr{\insertimageboxed}{#2}{Direccion de la imagen no definida}%
	\emptyvarerr{\insertimageboxed}{#3}{Parametros de la imagen no definidos}%
	\emptyvarerr{\insertimageboxed}{#4}{Ancho de la linea no definido}%
	\checkoutsideenvimage%
	\corevspacevarcm{\marginimagetop}%
	\begin{samepage}%
	\begin{figure}[H]%
		\begingroup%
			\setlength{\fboxsep}{0 pt}%
			\setlength{\fboxrule}{#4 pt}%
			\centering%
			\ifthenelse{\equal{\GLOBALimagelink}{}}{ % Sin link
				\fbox{}%
			}{ % Con link
				\fbox{\href{\GLOBALimagelink}{}}%
			}%
		\endgroup%
		\ifx\hfuzz#5\hfuzz%
			\corevspacevarcm{\captionlessmarginimage}%
		\else%
			\hspace{0cm}%
			\corevspacevarcm{\captionmarginimage}%
			\ifthenelse{\equal{\GLOBALcaptiondefn}{EMPTY-VAR}}{\caption{#5 #1}}{\caption[\GLOBALcaptiondefn]{#5 #1}}%
		\fi%
	\end{figure}
	\corevspacevarcm{\marginimagebottom}%
	\end{samepage}
	\resetindexcaption%
}

% Insertar una imagen animada
% 	#1	Label (opcional)
%	#2	Dirección de la imagen animada
%	#3	Parámetros de la imagen
%	#4	FPS de la imagen
%	#5	Total imágenes no definido
%	#6	Leyenda de la imagen (opcional)
\newcommand{\insertanimatedimage}[6][]{%
	\insertanimatedimageboxed[#1]{#2}{#3}{#4}{#5}{0}{#6}%
}

% Insertar una imagen animada
% 	#1	Label (opcional)
%	#2	Dirección de la imagen animada
%	#3	Parámetros de la imagen
%	#4	FPS de la imagen
%	#5	Total imágenes no definido
%	#6	Ancho de la línea (en pt)
%	#7	Leyenda de la imagen (opcional)
\newcommand{\insertanimatedimageboxed}[7][]{%
	\emptyvarerr{\insertanimatedimage}{#2}{Direccion de la imagen no definida}%
	\emptyvarerr{\insertanimatedimage}{#3}{Parametros de la imagen no definidos}%
	\emptyvarerr{\insertanimatedimage}{#4}{FPS no definido}%
	\emptyvarerr{\insertanimatedimage}{#5}{Total imagenes no definido}%
	\emptyvarerr{\insertanimatedimage}{#6}{Ancho de la línea no definido}%
	\checkoutsideenvimage%
	\corevspacevarcm{\marginimagetop}%
	\begin{samepage}%
	\begin{figure}[H]%
		\begingroup%
			\setlength{\fboxsep}{0 pt}%
			\setlength{\fboxrule}{#6 pt}%
			\centering%
			\ifthenelse{\equal{\animatedimagecontrols}{true}}{ % Muestra los controles
				\ifthenelse{\equal{\animatedimageloop}{true}}{ % Con loop
					\ifthenelse{\equal{\animatedimageautoplay}{true}}{ % Con autoplay
						\fbox{\animategraphics[controls,loop,autoplay,#3]{#4}{#2-}{0}{#5}}%	
					}{ % Sin autoplay
						\fbox{\animategraphics[controls,loop,#3]{#4}{#2-}{0}{#5}}%
					}%
				}{ % Sin loop
					\ifthenelse{\equal{\animatedimageautoplay}{true}}{ % Con autoplay
						\fbox{\animategraphics[controls,autoplay,#3]{#4}{#2-}{0}{#5}}%
					}{ % Sin autoplay
						\fbox{\animategraphics[controls,#3]{#4}{#2-}{0}{#5}}%
					}%
				}%
			}{ % Sin controles
				\ifthenelse{\equal{\animatedimageloop}{true}}{ % Con loop
					\ifthenelse{\equal{\animatedimageautoplay}{true}}{ % Con autoplay
						\fbox{\animategraphics[loop,autoplay,#3]{#4}{#2-}{0}{#5}}%
					}{ % Sin autoplay
						\fbox{\animategraphics[loop,#3]{#4}{#2-}{0}{#5}}%
					}%
				}{ % Sin loop
					\ifthenelse{\equal{\animatedimageautoplay}{true}}{ % Con autoplay
						\fbox{\animategraphics[autoplay,#3]{#4}{#2-}{0}{#5}}%
					}{ % Sin autoplay
						\fbox{\animategraphics[#3]{#4}{#2-}{0}{#5}}%
					}%
				}%
			}%
		\endgroup%
		\ifx\hfuzz#7\hfuzz%
			\corevspacevarcm{\captionlessmarginimage}%
		\else%
			\hspace{0cm}%
			\corevspacevarcm{\captionmarginimage}%
			\ifthenelse{\equal{\GLOBALcaptiondefn}{EMPTY-VAR}}{\caption{#7 #1}}{\caption[\GLOBALcaptiondefn]{#7 #1}}%
		\fi%
	\end{figure}
	\corevspacevarcm{\marginimagebottom}%
	\end{samepage}
	\resetindexcaption%
}

% Insertar una imagen con link
% 	#1	Label (opcional)
%	#2	Dirección de la imagen
%	#3	Parámetros de la imagen
%	#4	Link de la imagen
%	#5	Leyenda de la imagen (opcional)
\newcommand{\insertimagelink}[5][]{%
	\insertimagelinkboxed[#1]{#2}{#3}{0}{#4}{#5}%
}

% Insertar una imagen con recuadro con link
% 	#1	Label (opcional)
%	#2	Dirección de la imagen
%	#3	Parámetros de la imagen
%	#4	Ancho de la línea (en pt)
%	#5	Link de la imagen
%	#6	Leyenda de la imagen (opcional)
\newcommand{\insertimagelinkboxed}[6][]{%
	\global\def\GLOBALimagelink {#5}%
	\insertimageboxed[#1]{#2}{#3}{#4}{#6}%
	\global\def\GLOBALimagelink {}%
}

% Insertar una imagen completa en un entorno multicol
% 	#1	Label (opcional)
%	#2	Dirección de la imagen
%	#3	Parámetros de la imagen
%	#4	Posición, "bottom" o "top"
%	#5	Leyenda de la imagen (opcional)
\newcommand{\insertimagemc}[5][]{%
	\insertimageboxedmc[#1]{#2}{#3}{0}{#4}{#5}%
}

% Insertar una imagen completa con recuadro en un entorno multicol
% 	#1	Label (opcional)
%	#2	Dirección de la imagen
%	#3	Parámetros de la imagen
%	#4	Ancho de la línea (en pt)
%	#5	Posición, "bottom", "top", "fixed2", "fixed3", "fixed4"
%	#6	Leyenda de la imagen (opcional)
\newcommand{\insertimageboxedmc}[6][]{%
	\emptyvarerr{\insertimageboxedmc}{#2}{Direccion de la imagen no definida}%
	\emptyvarerr{\insertimageboxedmc}{#3}{Parametros de la imagen no definidos}%
	\emptyvarerr{\insertimageboxedmc}{#4}{Ancho de la linea no definido}%
	\emptyvarerr{\insertimageboxedmc}{#5}{Posicion de la imagen no definida}%
	\checkoutsideenvimage%
	\checkinsidemulticol%
	\checkoutsideappendix%
	\setcaptionmargincm{\captionlrmarginmc}%
	\ifthenelse{\equal{#5}{bottom}}{%
		\begin{samepage}%
		\begin{figure*}[b]
	}{%
	\ifthenelse{\equal{#5}{top}}{%
		\begin{samepage}%
		\begin{figure*}[t]
	}{%
	\ifthenelse{\equal{#5}{fixed2}}{%
		\end{multicols}
		\begin{samepage}%
		\begin{figure*}[h]
	}{%
	\ifthenelse{\equal{#5}{fixed2b}}{%
		\end{multicols}
		\begin{samepage}%
		\begin{figure*}[b]
	}{%
	\ifthenelse{\equal{#5}{fixed2t}}{%
		\end{multicols}
		\begin{samepage}%
		\begin{figure*}[t]
	}{%
	\ifthenelse{\equal{#5}{fixed3}}{%
		\end{multicols}
		\begin{samepage}%
		\begin{figure*}[h]
	}{%
	\ifthenelse{\equal{#5}{fixed3b}}{%
		\end{multicols}
		\begin{samepage}%
		\begin{figure*}[b]
	}{%
	\ifthenelse{\equal{#5}{fixed3t}}{%
		\end{multicols}
		\begin{samepage}%
		\begin{figure*}[t]
	}{%
	\ifthenelse{\equal{#5}{fixed4}}{%
		\end{multicols}
		\begin{samepage}%
		\begin{figure*}[h]
	}{%
	\ifthenelse{\equal{#5}{fixed4b}}{%
		\end{multicols}
		\begin{samepage}%
		\begin{figure*}[h]
	}{%
	\ifthenelse{\equal{#5}{fixed4t}}{%
		\end{multicols}
		\begin{samepage}%
		\begin{figure*}[h]
	}{%
		\errmessage{LaTeX Warning: Posicion de imagen invalida, valores esperados: bottom,top,fixed2,fixed2b,fixed2t,fixed3,fixed3b,fixed3t,fixed4,fixed4b,fixed4t}
		\stop}}}}}}}}}}
	}%
		\begingroup%
			\setlength{\fboxsep}{0 pt}%
			\setlength{\fboxrule}{#4 pt}%
			\centering%
			\fbox{}%
		\endgroup%
		\ifx\hfuzz#6\hfuzz%
			\corevspacevarcm{\captionlessmarginimage}%
		\else%
			\hspace{0cm}%
			\corevspacevarcm{\captionmarginimage}%
			\ifthenelse{\equal{\GLOBALcaptiondefn}{EMPTY-VAR}}{\caption{#6 #1}}{\caption[\GLOBALcaptiondefn]{#6 #1}}%
		\fi%
	\end{figure*}
	\end{samepage}
	\ifthenelse{\equal{#5}{fixed2}}{%
		\begin{multicols}{2}%
	}{%
	\ifthenelse{\equal{#5}{fixed2b}}{%
		\begin{multicols}{2}%
	}{%
	\ifthenelse{\equal{#5}{fixed2t}}{%
		\begin{multicols}{2}%
	}{%
	\ifthenelse{\equal{#5}{fixed3}}{%
		\begin{multicols}{3}%
	}{%
	\ifthenelse{\equal{#5}{fixed3b}}{%
		\begin{multicols}{3}%
	}{%
	\ifthenelse{\equal{#5}{fixed3t}}{%
		\begin{multicols}{3}%
	}{%
	\ifthenelse{\equal{#5}{fixed4}}{%
		\begin{multicols}{4}%
	}{%
	\ifthenelse{\equal{#5}{fixed4b}}{%
		\begin{multicols}{4}%
	}{%
	\ifthenelse{\equal{#5}{fixed4t}}{%
		\begin{multicols}{4}%
	}{%
	}}}}}}}}}%
	\setcaptionmargincm{\captionlrmargin}%
	\resetindexcaption%
}

% Insertar una imagen dentro de una tabla
%	#1	Dirección de la imagen
%	#2	Parámetros de la imagen
\newcommand{\inserttableimage}[2]{%
	\inserttableimageboxed{#1}{#2}{0}%
}

% Insertar una imagen dentro de una tabla con recuadro
%	#1	Dirección de la imagen
%	#2	Parámetros de la imagen
%	#3	Ancho de la línea (en pt)
\newcommand{\inserttableimageboxed}[3]{%
	\emptyvarerr{\inserttableimageboxed}{#1}{Direccion de la imagen no definida}%
	\emptyvarerr{\inserttableimageboxed}{#2}{Parametros de la imagen no definidos}%
	\emptyvarerr{\inserttableimageboxed}{#3}{Ancho de la linea no definido}%
	\checkoutsideenvimage%
	\begingroup%
	\setlength{\fboxsep}{0 pt}%
	\setlength{\fboxrule}{#3 pt}%
	\raisebox{-1\totalheight}{\fbox{}}%
	\endgroup%
	\resetindexcaption%
}

% Insertar una imagen a la izquierda, escalada, ancho fijo
% 	#1	Label (opcional)
%	#2	Dirección de la imagen
%	#3	Ancho de la imagen (en linewidth)
%	#4	Leyenda de la imagen (opcional)
\newcommand{\insertimageleft}[4][]{%
	\insertimageleftboxed[#1]{#2}{#3}{0}{#4}%
}

% Insertar una imagen a la izquierda, escalada, ancho fijo
% 	#1	Label (opcional)
%	#2	Dirección de la imagen
%	#3	Ancho de la imagen (en linewidth)
%	#4	Ancho de la línea (en pt)
%	#5	Leyenda de la imagen (opcional)
\newcommand{\insertimageleftboxed}[5][]{%
	\emptyvarerr{\insertimageleftboxed}{#2}{Direccion de la imagen no definida}%
	\emptyvarerr{\insertimageleftboxed}{#3}{Ancho de la imagen no definido}%
	\emptyvarerr{\insertimageleftboxed}{#4}{Ancho de la linea no definido}%
	\checkoutsideenvimage%
	~%
	\vspace{-\baselineskip}%
	\par%
	\begin{wrapfigure}{l}{#3\linewidth}%
		\setcaptionmargincm{0}%
		\ifthenelse{\equal{\figurecaptiontop}{true}}{}{%
			\vspace{\marginfloatimages pt}%
		}%
		\begingroup%
			\setlength{\fboxsep}{0 pt}%
			\setlength{\fboxrule}{#4 pt}%
			\centering%
			\fbox{}%
		\endgroup%
		\ifx\hfuzz#5\hfuzz%
			\corevspacevarcm{\captionlessmarginimage}%
		\else%
			\corevspacevarcm{\captionmarginimage}%
			\ifthenelse{\equal{\GLOBALcaptiondefn}{EMPTY-VAR}}{\caption{#5 #1}}{\caption[\GLOBALcaptiondefn]{#5 #1}}%
		\fi%
	\end{wrapfigure}
	\setcaptionmargincm{\captionlrmargin}%
	\resetindexcaption%
}

% Insertar una imagen a la izquierda, ajustada en un número de líneas, escalada, ancho fijo
% 	#1	Label (opcional)
%	#2	Dirección de la imagen
%	#3	Ancho de la imagen (en linewidth)
%	#4	Altura en líneas de la imagen
%	#5	Leyenda de la imagen (opcional)
\newcommand{\insertimageleftline}[5][]{%
	\insertimageleftlineboxed[#1]{#2}{#3}{0}{#4}{#5}%
}

% Insertar una imagen recuadrada a la izquierda, ajustada en un número de líneas, escalada, ancho fijo
% 	#1	Label (opcional)
%	#2	Dirección de la imagen
%	#3	Ancho de la imagen (en linewidth)
%	#4	Ancho de la línea (en pt)
%	#5	Altura en líneas de la imagen
%	#6	Leyenda de la imagen (opcional)
\newcommand{\insertimageleftlineboxed}[6][]{%
	\emptyvarerr{\insertimageleftlineboxed}{#2}{Direccion de la imagen no definida}%
	\emptyvarerr{\insertimageleftlineboxed}{#3}{Ancho de la imagen no definido}%
	\emptyvarerr{\insertimageleftlineboxed}{#4}{Ancho de la linea no definido}%
	\emptyvarerr{\insertimageleftlineboxed}{#5}{Altura en lineas de la imagen flotante izquierda no definida}
	\checkoutsideenvimage%
	~%
	\vspace{-\baselineskip}%
	\par%
	\begin{wrapfigure}[#5]{l}{#3\linewidth}%
		\setcaptionmargincm{0}%
		\ifthenelse{\equal{\figurecaptiontop}{true}}{}{%
			\vspace{\marginfloatimages pt}}%
		\begingroup%
			\setlength{\fboxsep}{0 pt}%
			\setlength{\fboxrule}{#4 pt}%
			\centering%
			\fbox{}%
		\endgroup%
		\ifx\hfuzz#6\hfuzz%
			\corevspacevarcm{\captionlessmarginimage}%
		\else%
			\corevspacevarcm{\captionmarginimage}%
			\ifthenelse{\equal{\GLOBALcaptiondefn}{EMPTY-VAR}}{\caption{#6 #1}}{\caption[\GLOBALcaptiondefn]{#6 #1}}%
		\fi%
	\end{wrapfigure}
	\setcaptionmargincm{\captionlrmargin}%
	\resetindexcaption%
}

% Insertar una imagen a la derecha, escalada, ancho fijo
% 	#1	Label (opcional)
%	#2	Dirección de la imagen
%	#3	Ancho de la imagen (en linewidth)
%	#4	Leyenda de la imagen (opcional)
\newcommand{\insertimageright}[4][]{%
	\insertimagerightboxed[#1]{#2}{#3}{0}{#4}%
}

% Insertar una imagen recuadrada a la derecha, escalada, ancho fijo
% 	#1	Label (opcional)
%	#2	Dirección de la imagen
%	#3	Ancho de la imagen (en linewidth)
%	#4	Ancho de la línea (en pt)
%	#5	Leyenda de la imagen (opcional)
\newcommand{\insertimagerightboxed}[5][]{%
	\emptyvarerr{\insertimagerightboxed}{#2}{Direccion de la imagen no definida}%
	\emptyvarerr{\insertimagerightboxed}{#3}{Ancho de la imagen no defindo}%
	\emptyvarerr{\insertimagerightboxed}{#4}{Ancho de la linea no definido}%
	\checkoutsideenvimage%
	~%
	\vspace{-\baselineskip}%
	\par%
	\begin{wrapfigure}{r}{#3\linewidth}%
		\setcaptionmargincm{0}%
		\ifthenelse{\equal{\figurecaptiontop}{true}}{}{%
			\vspace{\marginfloatimages pt}%
		}%
		\begingroup%
			\setlength{\fboxsep}{0 pt}%
			\setlength{\fboxrule}{#4 pt}%
			\centering%
			\fbox{}%
		\endgroup%
		\ifx\hfuzz#5\hfuzz%
			\corevspacevarcm{\captionlessmarginimage}%
		\else%
			\corevspacevarcm{\captionmarginimage}%
			\ifthenelse{\equal{\GLOBALcaptiondefn}{EMPTY-VAR}}{\caption{#5 #1}}{\caption[\GLOBALcaptiondefn]{#5 #1}}%
		\fi%
	\end{wrapfigure}
	\setcaptionmargincm{\captionlrmargin}%
	\resetindexcaption%
}

% Insertar una imagen a la derecha, ajustada en un número de líneas, escalada, ancho fijo
% 	#1	Label (opcional)
%	#2	Dirección de la imagen
%	#3	Ancho de la imagen (en linewidth)
%	#4	Altura en líneas de la imagen
%	#5	Leyenda de la imagen (opcional)
\newcommand{\insertimagerightline}[5][]{%
	\insertimagerightlineboxed[#1]{#2}{#3}{0}{#4}{#5}%
}

% Insertar una imagen recuadrada a la derecha, ajustada en un número de líneas, escalada, ancho fijo
% 	#1	Label (opcional)
%	#2	Dirección de la imagen
%	#3	Ancho de la imagen (en linewidth)
%	#4	Ancho de la línea (en pt)
%	#5	Altura en líneas de la imagen
%	#6	Leyenda de la imagen (opcional)
\newcommand{\insertimagerightlineboxed}[6][]{%
	\emptyvarerr{\insertimagerightlineboxed}{#2}{Direccion de la imagen no definida}%
	\emptyvarerr{\insertimagerightlineboxed}{#3}{Ancho de la imagen no defindo}%
	\emptyvarerr{\insertimagerightlineboxed}{#4}{Ancho de la linea no definido}%
	\emptyvarerr{\insertimagerightlineboxed}{#5}{Altura en lineas de la imagen flotante derecha no definida}%
	\checkoutsideenvimage%
	~%
	\vspace{-\baselineskip}%
	\par%
	\begin{wrapfigure}[#5]{r}{#3\linewidth}%
		\setcaptionmargincm{0}%
		\ifthenelse{\equal{\figurecaptiontop}{true}}{}{%
			\vspace{\marginfloatimages pt}%
		}%
		\begingroup%
			\setlength{\fboxsep}{0 pt}%
			\setlength{\fboxrule}{#4 pt}%
			\centering%
			\fbox{}%
		\endgroup%
		\ifx\hfuzz#6\hfuzz%
			\corevspacevarcm{\captionlessmarginimage}%
		\else%
			\corevspacevarcm{\captionmarginimage}%
			\ifthenelse{\equal{\GLOBALcaptiondefn}{EMPTY-VAR}}{\caption{#6 #1}}{\caption[\GLOBALcaptiondefn]{#6 #1}}%
		\fi%
	\end{wrapfigure}
	\setcaptionmargincm{\captionlrmargin}%
	\resetindexcaption%
}

% Insertar una imagen a la izquierda, propiedades variables
% 	#1	Label (opcional)
%	#2	Dirección de la imagen
%	#3	Ancho del objeto
%	#4	Propiedades de la imagen
%	#5	Leyenda de la imagen (opcional)
\newcommand{\insertimageleftp}[5][]{%
	\xspace ~ \\%
	\vspace{-2\baselineskip}%
	\par%
	\insertimageleftboxedp[#1]{#2}{#3}{#4}{0}{#5}%
}

% Insertar una imagen a la izquierda, propiedades variables
% 	#1	Label (opcional)
%	#2	Dirección de la imagen
%	#3	Ancho del objeto
%	#4	Propiedades de la imagen
%	#5	Ancho de la línea (en pt)
%	#6	Leyenda de la imagen (opcional)
\newcommand{\insertimageleftboxedp}[6][]{%
	\emptyvarerr{\insertimageleftboxedp}{#2}{Direccion de la imagen no definida}%
	\emptyvarerr{\insertimageleftboxedp}{#3}{Ancho del objeto no definido}%
	\emptyvarerr{\insertimageleftboxedp}{#4}{Propiedades de la imagen no defindos}%
	\emptyvarerr{\insertimageleftboxedp}{#5}{Ancho de la linea no definido}%
	\checkoutsideenvimage%
	~%
	\vspace{-\baselineskip}%
	\par%
	\begin{wrapfigure}{l}{#3}%
		\setcaptionmargincm{0}%
		\ifthenelse{\equal{\figurecaptiontop}{true}}{}{%
			\vspace{\marginfloatimages pt}%
		}%
		\begingroup%
			\setlength{\fboxsep}{0 pt}%
			\setlength{\fboxrule}{#5 pt}%
			\centering%
			\fbox{}%
		\endgroup%
		\ifx\hfuzz#6\hfuzz%
			\corevspacevarcm{\captionlessmarginimage}%
		\else%
			\corevspacevarcm{\captionmarginimage}%
			\ifthenelse{\equal{\GLOBALcaptiondefn}{EMPTY-VAR}}{\caption{#6 #1}}{\caption[\GLOBALcaptiondefn]{#6 #1}}%
		\fi%
	\end{wrapfigure}
	\setcaptionmargincm{\captionlrmargin}%
	\resetindexcaption%
}

% Insertar una imagen a la izquierda, ajustada en un número de líneas, propiedades variables
% 	#1	Label (opcional)
%	#2	Dirección de la imagen
%	#3	Ancho del objeto
%	#4	Propiedades de la imagen
%	#5	Altura en líneas de la imagen
%	#6	Leyenda de la imagen (opcional)
\newcommand{\insertimageleftlinep}[6][]{%
	\insertimageleftlineboxedp[#1]{#2}{#3}{#4}{0}{#5}{#6}%
}

% Insertar una imagen recuadrada a la izquierda, ajustada en un número de líneas, propiedades variables
% 	#1	Label (opcional)
%	#2	Dirección de la imagen
%	#3	Ancho del objeto
%	#4	Propiedades de la imagen
%	#5	Ancho de la línea (en pt)
%	#6	Altura en líneas de la imagen
%	#7	Leyenda de la imagen (opcional)
\newcommand{\insertimageleftlineboxedp}[7][]{%
	\emptyvarerr{\insertimageleftlineboxedp}{#2}{Direccion de la imagen no definida}%
	\emptyvarerr{\insertimageleftlineboxedp}{#3}{Ancho del objeto no definido}%
	\emptyvarerr{\insertimageleftlineboxedp}{#4}{Propiedades de la imagen no definidos}%
	\emptyvarerr{\insertimageleftlineboxedp}{#5}{Ancho de la linea no definido}%
	\emptyvarerr{\insertimageleftlineboxedp}{#6}{Altura en lineas de la imagen flotante izquierda no definida}%
	\checkoutsideenvimage%
	~%
	\vspace{-\baselineskip}%
	\par%
	\begin{wrapfigure}[#6]{l}{#3}%
		\setcaptionmargincm{0}%
		\ifthenelse{\equal{\figurecaptiontop}{true}}{}{%
			\vspace{\marginfloatimages pt}%
		}%
		\begingroup%
			\setlength{\fboxsep}{0 pt}%
			\setlength{\fboxrule}{#5 pt}%
			\centering%
			\fbox{}%
		\endgroup%
		\ifx\hfuzz#7\hfuzz%
			\corevspacevarcm{\captionlessmarginimage}%
		\else%
			\corevspacevarcm{\captionmarginimage}%
			\ifthenelse{\equal{\GLOBALcaptiondefn}{EMPTY-VAR}}{\caption{#7 #1}}{\caption[\GLOBALcaptiondefn]{#7 #1}}%
		\fi%
	\end{wrapfigure}
	\setcaptionmargincm{\captionlrmargin}%
	\resetindexcaption%
}

% Insertar una imagen a la derecha, propiedades variables
% 	#1	Label (opcional)
%	#2	Dirección de la imagen
%	#3	Ancho del objeto (en cm)
%	#4	Propiedades de la imagen
%	#5	Leyenda de la imagen (opcional)
\newcommand{\insertimagerightp}[5][]{%
	\xspace ~ \\%
	\vspace{-2\baselineskip}%
	\par%
	\insertimagerightboxedp[#1]{#2}{#3}{#4}{0}{#5}%
}

% Insertar una imagen recuadrada a la derecha, propiedades variables
% 	#1	Label (opcional)
%	#2	Dirección de la imagen
%	#3	Ancho del objeto
%	#4	Propiedades de la imagen
%	#5	Ancho de la línea (en pt)
%	#6	Leyenda de la imagen (opcional)
\newcommand{\insertimagerightboxedp}[6][]{%
	\emptyvarerr{\insertimagerightboxedp}{#2}{Direccion de la imagen no definida}%
	\emptyvarerr{\insertimagerightboxedp}{#3}{Ancho del objeto no definido}%
	\emptyvarerr{\insertimagerightboxedp}{#4}{Propiedades de la imagen no definidos}%
	\emptyvarerr{\insertimagerightboxedp}{#5}{Ancho de la linea no definido}%
	\checkoutsideenvimage%
	~%
	\vspace{-\baselineskip}%
	\par%
	\begin{wrapfigure}{r}{#3}%
		\setcaptionmargincm{0}%
		\ifthenelse{\equal{\figurecaptiontop}{true}}{}{%
			\vspace{\marginfloatimages pt}%
		}%
		\begingroup%
			\setlength{\fboxsep}{0 pt}%
			\setlength{\fboxrule}{#5 pt}%
			\centering%
			\fbox{}%
		\endgroup%
		\ifx\hfuzz#6\hfuzz%
			\corevspacevarcm{\captionlessmarginimage}%
		\else%
			\corevspacevarcm{\captionmarginimage}%
			\ifthenelse{\equal{\GLOBALcaptiondefn}{EMPTY-VAR}}{\caption{#6 #1}}{\caption[\GLOBALcaptiondefn]{#6 #1}}%
		\fi%
	\end{wrapfigure}
	\setcaptionmargincm{\captionlrmargin}%
	\resetindexcaption%
}

% Insertar una imagen a la derecha, ajustada en un número de líneas, propiedades variables
% 	#1	Label (opcional)
%	#2	Dirección de la imagen
%	#3	Ancho del objeto (en cm)
%	#4	Propiedades de la imagen
%	#5	Altura en líneas de la imagen
%	#6	Leyenda de la imagen (opcional)
\newcommand{\insertimagerightlinep}[6][]{%
	\insertimagerightlineboxedp[#1]{#2}{#3}{#4}{0}{#5}{#6}%
}

% Insertar una imagen recuadrada a la derecha, ajustada en un número de líneas, propiedades variables
% 	#1	Label (opcional)
%	#2	Dirección de la imagen
%	#3	Ancho del objeto
%	#4	Propiedades de la imagen
%	#5	Ancho de la línea (en pt)
%	#6	Altura en líneas de la imagen
%	#7	Leyenda de la imagen (opcional)
\newcommand{\insertimagerightlineboxedp}[7][]{%
	\emptyvarerr{\insertimagerightlineboxedp}{#2}{Direccion de la imagen no definida}%
	\emptyvarerr{\insertimagerightlineboxedp}{#3}{Ancho del objeto no definido}%
	\emptyvarerr{\insertimagerightlineboxedp}{#4}{Propiedades de la imagen no definidos}%
	\emptyvarerr{\insertimagerightlineboxedp}{#5}{Ancho de la linea no definido}%
	\emptyvarerr{\insertimagerightlineboxedp}{#6}{Altura en lineas de la imagen flotante derecha no definida}%
	\checkoutsideenvimage%
	~%
	\vspace{-\baselineskip}%
	\par%
	\begin{wrapfigure}[#6]{r}{#3}%
		\setcaptionmargincm{0}%
		\ifthenelse{\equal{\figurecaptiontop}{true}}{}{%
			\vspace{\marginfloatimages pt}%
		}%
		\begingroup%
			\setlength{\fboxsep}{0 pt}%
			\setlength{\fboxrule}{#5 pt}%
			\centering%
			\fbox{}%
		\endgroup%
		\ifx\hfuzz#7\hfuzz%
			\corevspacevarcm{\captionlessmarginimage}%
		\else%
			\corevspacevarcm{\captionmarginimage}%
			\ifthenelse{\equal{\GLOBALcaptiondefn}{EMPTY-VAR}}{\caption{#7 #1}}{\caption[\GLOBALcaptiondefn]{#7 #1}}%
		\fi%
	\end{wrapfigure}
	\setcaptionmargincm{\captionlrmargin}%
	\resetindexcaption%
}

% Inserta una imagen con parametros keyvals almacenados en una variable
% 	#1	Parámetros (keyvals)
%	#2	Dirección de la imagen
\newcommand{\coreinsertkeyimage}[2]{%
	\expandafter\includegraphics\expandafter[#1]{\expandafter#2}%
}

% Define la clave resolution al insertar imágenes
\makeatletter
\define@key{Gin}{resolution}{\pdfimageresolution=#1\relax}
\makeatother

% Activa la numeración en las secciones
\def\coreintializetitlenumbering {%
	% Capítulo
	\renewcommand{\thechapter}{\GLOBALformatnumchapter{chapter}}
	% Section
	\ifthenelse{\equal{\GLOBALchapternumenabled}{false}}{%
		\renewcommand{\thesection}{%
			\GLOBALformatnumsection{section}%
		}%
	}{%
		\renewcommand{\thesection}{%
			\thechapter\charbetwchaptersection\GLOBALformatnumsection{section}%
		}%
	}%
	% Subsection
	\ifthenelse{\equal{\GLOBALsectionanumenabled}{true}}{%
		\renewcommand{\thesubsection}{%
			\GLOBALformatnumssection{subsection}%
		}%
	}{%
		\renewcommand{\thesubsection}{%
			\thesection\charbetwsectionsubsection\GLOBALformatnumssection{subsection}%
		}%
	}%
	% Subsubsection
	\ifthenelse{\equal{\GLOBALsubsectionanumenabled}{true}}{%
		\renewcommand{\thesubsubsection}{%
			\GLOBALformatnumsssection{subsubsection}%
		}%
	}{%
		\renewcommand{\thesubsubsection}{%
			\thesubsection\charbetwsubsectionssect\GLOBALformatnumsssection{subsubsection}%
		}%
	}%
	% Subsubsubsection
	\ifthenelse{\equal{\GLOBALsubsubsectionanumenabled}{true}}{%
		\renewcommand{\thesubsubsubsection}{%
			\GLOBALformatnumssssection{subsubsubsection}%
		}%
	}{%
		\renewcommand{\thesubsubsubsection}{%
			\thesubsubsection\charbetwssectionsssect\GLOBALformatnumssssection{subsubsubsection}%
		}%
	}%
	\hbadness=10000%
}

% Parcha el formato de capítulos
\pretocmd{\chapter}{%
	\ifthenelse{\equal{\showsectioncaptioncode}{chap}}{ % Reinicia código fuente
		\addtocounter{templateListings}{\value{lstlisting}}%
		\setcounter{lstlisting}{0}%
	}{}%
	\ifthenelse{\equal{\showsectioncaptioneqn}{chap}}{ % Reinicia ecuaciones
		\addtocounter{templateEquations}{\value{equation}}%
		\setcounter{equation}{0}%
	}{}%
	\ifthenelse{\equal{\equationrestart}{chap}}{ % Reinicia ecuaciones
		\addtocounter{templateEquations}{\value{equation}}%
		\setcounter{equation}{0}%
	}{}%
	\ifthenelse{\equal{\showsectioncaptionfig}{chap}}{ % Reinicia figuras
		\addtocounter{templateFigures}{\value{figure}}%
		\setcounter{figure}{0}%
	}{}%
	\ifthenelse{\equal{\showsectioncaptiontab}{chap}}{ % Reinicia tablas
		\addtocounter{templateTables}{\value{table}}%
		\setcounter{table}{0}%
	}{}%
	\global\def\GLOBALchapternumenabled {true}%
	\global\def\GLOBALsectionanumenabled {false}%
	\global\def\GLOBALsubsectionanumenabled {false}%
	\global\def\GLOBALsubsubsectionanumenabled {false}%
	\coreintializetitlenumbering%
}{}{}

% Parcha el formato de secciones al pasar desde una anum, vuelve a activar número
% de la sección
\pretocmd{\section}{%
	\ifthenelse{\equal{\showsectioncaptioncode}{sec}}{ % Reinicia código fuente
		\addtocounter{templateListings}{\value{lstlisting}}%
		\setcounter{lstlisting}{0}%
	}{}%
	\ifthenelse{\equal{\showsectioncaptioneqn}{sec}}{ % Reinicia ecuaciones
		\addtocounter{templateEquations}{\value{equation}}%
		\setcounter{equation}{0}%
	}{}%
	\ifthenelse{\equal{\equationrestart}{sec}}{ % Reinicia ecuaciones
		\addtocounter{templateEquations}{\value{equation}}%
		\setcounter{equation}{0}%
	}{}%
	\ifthenelse{\equal{\showsectioncaptionfig}{sec}}{ % Reinicia figuras
		\addtocounter{templateFigures}{\value{figure}}%
		\setcounter{figure}{0}%
	}{}%
	\ifthenelse{\equal{\showsectioncaptiontab}{sec}}{ % Reinicia tablas
		\addtocounter{templateTables}{\value{table}}%
		\setcounter{table}{0}%
	}{}%
	\global\def\GLOBALsectionanumenabled {false}%
	\global\def\GLOBALsubsectionanumenabled {false}%
	\global\def\GLOBALsubsubsectionanumenabled {false}%
	\coreintializetitlenumbering%
}{}{}

% Comienza nueva subsección, si está dentro de una sectionanum entonces no dibuja el
% número de sección, si no entonces dibuja el número de forma normal
\pretocmd{\subsection}{%
	\ifthenelse{\equal{\showsectioncaptioncode}{ssec}}{ % Reinicia código fuente
		\addtocounter{templateListings}{\value{lstlisting}}%
		\setcounter{lstlisting}{0}%
	}{}%
	\ifthenelse{\equal{\showsectioncaptioneqn}{ssec}}{ % Reinicia ecuaciones
		\addtocounter{templateEquations}{\value{equation}}%
		\setcounter{equation}{0}%
	}{}%
	\ifthenelse{\equal{\equationrestart}{ssec}}{ % Reinicia ecuaciones
		\addtocounter{templateEquations}{\value{equation}}%
		\setcounter{equation}{0}%
	}{}%
	\ifthenelse{\equal{\showsectioncaptionfig}{ssec}}{ % Reinicia figuras
		\addtocounter{templateFigures}{\value{figure}}%
		\setcounter{figure}{0}%
	}{}%
	\ifthenelse{\equal{\showsectioncaptiontab}{ssec}}{ % Reinicia tablas
		\addtocounter{templateTables}{\value{table}}%
		\setcounter{table}{0}%
	}{}%
	\global\def\GLOBALsubsectionanumenabled {false}%
	\global\def\GLOBALsubsubsectionanumenabled {false}%
	\coreintializetitlenumbering%
}{}{}

% Comienza nueva subsubsección, aquí hay varios casos:
%	- si está dentro de una subsección sin número ignora la sección
%	- si no, entonces puede estar dentro de una sección sin número o no, en ese caso
%	  debe evaluar ambas posibilidades
\pretocmd{\subsubsection}{%
	\ifthenelse{\equal{\showsectioncaptioncode}{sssec}}{ % Reinicia código fuente
		\addtocounter{templateListings}{\value{lstlisting}}%
		\setcounter{lstlisting}{0}%
	}{}%
	\ifthenelse{\equal{\showsectioncaptioneqn}{sssec}}{ % Reinicia ecuaciones
		\addtocounter{templateEquations}{\value{equation}}%
		\setcounter{equation}{0}%
	}{}%
	\ifthenelse{\equal{\equationrestart}{sssec}}{ % Reinicia ecuaciones
		\addtocounter{templateEquations}{\value{equation}}%
		\setcounter{equation}{0}%
	}{}%
	\ifthenelse{\equal{\showsectioncaptionfig}{sssec}}{ % Reinicia figuras
		\addtocounter{templateFigures}{\value{figure}}%
		\setcounter{figure}{0}%
	}{}%
	\ifthenelse{\equal{\showsectioncaptiontab}{sssec}}{ % Reinicia tablas
		\addtocounter{templateTables}{\value{table}}%
		\setcounter{table}{0}%
	}{}%
	\global\def\GLOBALsubsubsectionanumenabled {false}%
	\coreintializetitlenumbering%
}{}{}

% Parcha sub-sub-subsecciones
\pretocmd{\subsubsubsection}{%
	\ifthenelse{\equal{\showsectioncaptioncode}{ssssec}}{ % Reinicia código fuente
		\addtocounter{templateListings}{\value{lstlisting}}%
		\setcounter{lstlisting}{0}%
	}{}%
	\ifthenelse{\equal{\showsectioncaptioneqn}{ssssec}}{ % Reinicia ecuaciones
		\addtocounter{templateEquations}{\value{equation}}%
		\setcounter{equation}{0}%
	}{}%
	\ifthenelse{\equal{\equationrestart}{ssssec}}{ % Reinicia ecuaciones
		\addtocounter{templateEquations}{\value{equation}}%
		\setcounter{equation}{0}%
	}{}%
	\ifthenelse{\equal{\showsectioncaptionfig}{ssssec}}{ % Reinicia figuras
		\addtocounter{templateFigures}{\value{figure}}%
		\setcounter{figure}{0}%
	}{}%
	\ifthenelse{\equal{\showsectioncaptiontab}{ssssec}}{ % Reinicia tablas
		\addtocounter{templateTables}{\value{table}}%
		\setcounter{table}{0}%
	}{}%
}{}{}

% Insertar un título sin número
% 	#1	Título
\newcommand{\sectionanum}[1]{%
	\emptyvarerr{\sectionanum}{#1}{Titulo no definido}%
	\phantomsection%
	\needspace{3\baselineskip}%
	\section*{#1}%
	\addcontentsline{toc}{section}{#1}%
	\ifthenelse{\equal{\anumsecaddtocounter}{true}}{\stepcounter{section}}{}%
	\changeheadertitle{#1}%
	\setcounter{subsection}{0}%
	\global\def\GLOBALsectionanumenabled {true}%
	\coreintializetitlenumbering%
}

% Insertar un subtítulo sin número
% 	#1	Subtítulo
\newcommand{\subsectionanum}[1]{%
	\emptyvarerr{\subsectionanum}{#1}{Subtitulo no definido}%
	\subsection*{#1}%
	\addcontentsline{toc}{subsection}{#1}
	\ifthenelse{\equal{\anumsecaddtocounter}{true}}{\stepcounter{subsection}}{}%
	\setcounter{subsubsection}{0}%
	\global\def\GLOBALsubsectionanumenabled {true}%
	\coreintializetitlenumbering%
}

% Insertar un sub-subtítulo sin número
% 	#1	Sub-subtítulo
\newcommand{\subsubsectionanum}[1]{%
	\emptyvarerr{\subsubsectionanum}{#1}{Sub-subtitulo no definido}%
	\subsubsection*{#1}%
	\addcontentsline{toc}{subsubsection}{#1}%
	\ifthenelse{\equal{\anumsecaddtocounter}{true}}{\stepcounter{subsubsection}}{}%
	\setcounter{subsubsubsection}{0}%
	\global\def\GLOBALsubsubsectionanumenabled {true}%
	\coreintializetitlenumbering%
}

% Insertar un sub-sub-subtítulo sin número
% 	#1	Sub-sub-subtítulo
\newcommand{\subsubsubsectionanum}[1]{%
	\emptyvarerr{\subsubsubsectionanum}{#1}{Sub-sub-subtitulo no definido}%
	\subsubsubsection*{#1}%
	\addcontentsline{toc}{subsubsubsection}{#1}%
	\ifthenelse{\equal{\anumsecaddtocounter}{true}}{\stepcounter{subsubsubsection}}{}%
}

% Cambia el título del encabezado (header)
%	#1	Título
\newcommand{\changeheadertitle}[1]{%
	\emptyvarerr{\changeheadertitle}{#1}{Titulo no definido}%
	\markboth{#1}{}%
}

% Elimina el título del encabezado (header)
\newcommand{\clearheadertitle}{%
	\markboth{}{}%
}

% Crear un capítulo como una sección
%	#1	Título
\newcommand{\newchapter}[1]{%
	\emptyvarerr{\newchapter}{#1}{Titulo no definido}%
	\clearpage%
	\stepcounter{section}%
	\phantomsection%
	\needspace{3\baselineskip}%
	\vspace* {3cm}%
	\noindent {\huge{\textbf{\namechapter\ \thesection}}} \\%
	\vspace* {0.5cm} \\%
	\noindent {\Huge{\textbf{#1}}} \\%
	\vspace {0.5cm} \\%
	\addcontentsline{toc}{section}{\protect\numberline{\thesection}#1}%
	\markboth{#1}{}%
}

% Insertar párrafo
\newcommand{\newp}{%
	\hbadness=10000 \vspace{\baselinestretch\baselineskip} \par%
}

% Crea un salto de columna en el entorno multicol
%\newcommand{\newcolumn}{%
%	\checkinsidemulticol\vfill\null\columnbreak%
%}

% Salto de página en entorno multicol
\newcommand{\newpagemulticol}{%
	\newcolumn\newcolumn\clearpage%
}

% Redimensiona un ítem
% 	#1	Tamaño del nuevo objeto (En linewidth)
%	#2	Objeto a redimensionar
\newcommand{\itemresize}[2]{%
	\emptyvarerr{\itemresize}{#1}{Tamano del nuevo objeto no definido}%
	\emptyvarerr{\itemresize}{#2}{Objeto a redimensionar no definido}%
	\resizebox{#1\linewidth}{!}{#2}%
}

% Crea una página vacía sin header o footer
\newcommand{\insertemptypage}{%
	\clearpage%
	\thispagestyle{empty}%
	\null%
	\clearpage%
}

% Inserta una página vacía, aunque conserva header, footer y numeración
\newcommand{\insertblankpage}{%
	\clearpage%
	\null%
	\clearpage%
}

% Función personalizada \cleardoublepage
\def\corecleardoublepage {%
	\clearpage %
	\ifthenelse{\equal{\GLOBALtwoside}{true}}{%
		\ifodd\thepage %
		\else%
			\emptypagespredocformat%
		\fi%
	}{}%
}

% Ejecuta una función dependiendo si la página es par o impar
%	#1	Par
%	#2	Impar
\newcommand{\coretriggeronpage}[2]{%
	\ifthenelse{\isodd{\value{templatePageCounter}}}{%
		#2%
	}{%
		#1%
	}%
}

% Añade un archivo pdf con el header
%	#1	Parámetros (opcional)
%	#2	Nombre del archivo pdf
\newcommand{\includehfpdf}[2][]{%
	\includepdf[pagecommand={\pagestyle{fancy}},#1]{#2}%
}

% Añade un archivo pdf con el header
%	#1	Parámetros (opcional)
%	#2	Nombre del archivo pdf
\newcommand{\includefullhfpdf}[2][]{%
	\includepdf[pages=-,pagecommand={\pagestyle{fancy}},#1]{#2}%
}

% Inserta un texto entre comillas
%	#1 	Texto
\newcommand{\quotes}[1]{%
	\enquote*{#1}%
}

% Inserta un texto entre comillas y negrita
%	#1 	Texto
\newcommand{\quotesbf}[1]{%
	\quotes{\textbf{#1}}%
}

% Inserta un texto entre comillas e itálico
%	#1 	Texto
\newcommand{\quotesit}[1]{%
	\quotes{\textit{#1}}%
}

% Inserta un texto entre comillas y typewriter
%	#1 	Texto
\newcommand{\quotesttt}[1]{%
	\quotes{\texttt{#1}}%
}

% Inserta un texto entre comillas dobles
%	#1 	Texto
\newcommand{\doublequotes}[1]{%
	\enquote{#1}%
}

% Inserta una cita con texto elevado
%	#1	Cita
\newcommand{\scite}[1]{%
	\textsuperscript{\cite{#1}}%
}

% Fuerza la indentación
\newcommand{\forceindent}{%
	~ \\ %
	
	\vspace{-2\baselineskip}%
}

% Inserta un texto con el formato de enlace
% 	#1 	Enlace
\newcommand{\hreftext}[1]{%
	\ifthenelse{\equal{\fonturl}{same}}{%
		#1%
	}{%
	\ifthenelse{\equal{\fonturl}{tt}}{%
		\texttt{#1}%
	}{%
	\ifthenelse{\equal{\fonturl}{rm}}{%
		\textrm{#1}%
	}{%
	\ifthenelse{\equal{\fonturl}{sf}}{%
		\textsf{#1}%
	}{}}}}%
}

% Inserta un email con un link cliqueable
%	#1 	Dirección email
\newcommand{\insertemail}[1]{%
	\href{mailto:#1}{\hreftext{#1}}%
}

% Inserta un teléfono celular
%	#1	Teléfono celular
\newcommand{\insertphone}[1]{%
	\href{tel:#1}{\hreftext{#1}}%
}

% Reinicia el número de ecuaciones
\newcommand{\restartequation}{%
	\setcounter{equation}{0}%
}

% Desactiva el margen de las leyendas
\newcommand{\disablecaptionmargin}{%
	\setcaptionmargincm{0}%
}

% Reinicia el margen de las leyendas
\newcommand{\resetcaptionmargin}{%
	\setcaptionmargincm{\captionlrmargin}%
}
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

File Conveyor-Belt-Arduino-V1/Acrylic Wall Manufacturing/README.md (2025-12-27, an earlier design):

# Conveyor Belt Arduino - Acrylic Wall Manufacturing 🔦⚙️

*Author: Fernando Navarrete* ✍️

## English Version 🇺🇸

This folder contains the manufacturing files for the **Side Structural Walls** of the conveyor belt.

These components are critical as they hold the bearings (627zz) in place. We use **Laser Cutting** on **4mm Clear Acrylic** for precision and visibility.

### 📋 1. Part Specifications

| Specification | Value | Notes |
| --- | --- | --- |
| **Material** | Clear Acrylic (PMMA) | 4mm Thickness is critical. |
| **Stock Size** | **400mm x 300mm** | Standard purchased sheet size. |
| **Part Size** | 390mm x 100mm | *⚠️ Warning: Tight fit lengthwise (5mm margin/side).* |
| **Yield** | **3 Units per Sheet** | *Requires precise Zero alignment (See below).* |

### 📂 2. Files Included

* **`Soporte_Acr_lico.beam`**: **(Recommended)** Native Beam Studio project file. Contains the pre-configured layers for engraving and cutting. Ready to load into Flux Beambox.
* **`Soporte_Acr_lico.dxf`**: Standard Vector file. Use this if you need to import the geometry into other CAM software (LightBurn, RDWorks) or modify the CAD.
* **`Plano Fabricación paredes de acrílico V1.pdf`**: Technical drawing with dimensions and tolerances for quality control.
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

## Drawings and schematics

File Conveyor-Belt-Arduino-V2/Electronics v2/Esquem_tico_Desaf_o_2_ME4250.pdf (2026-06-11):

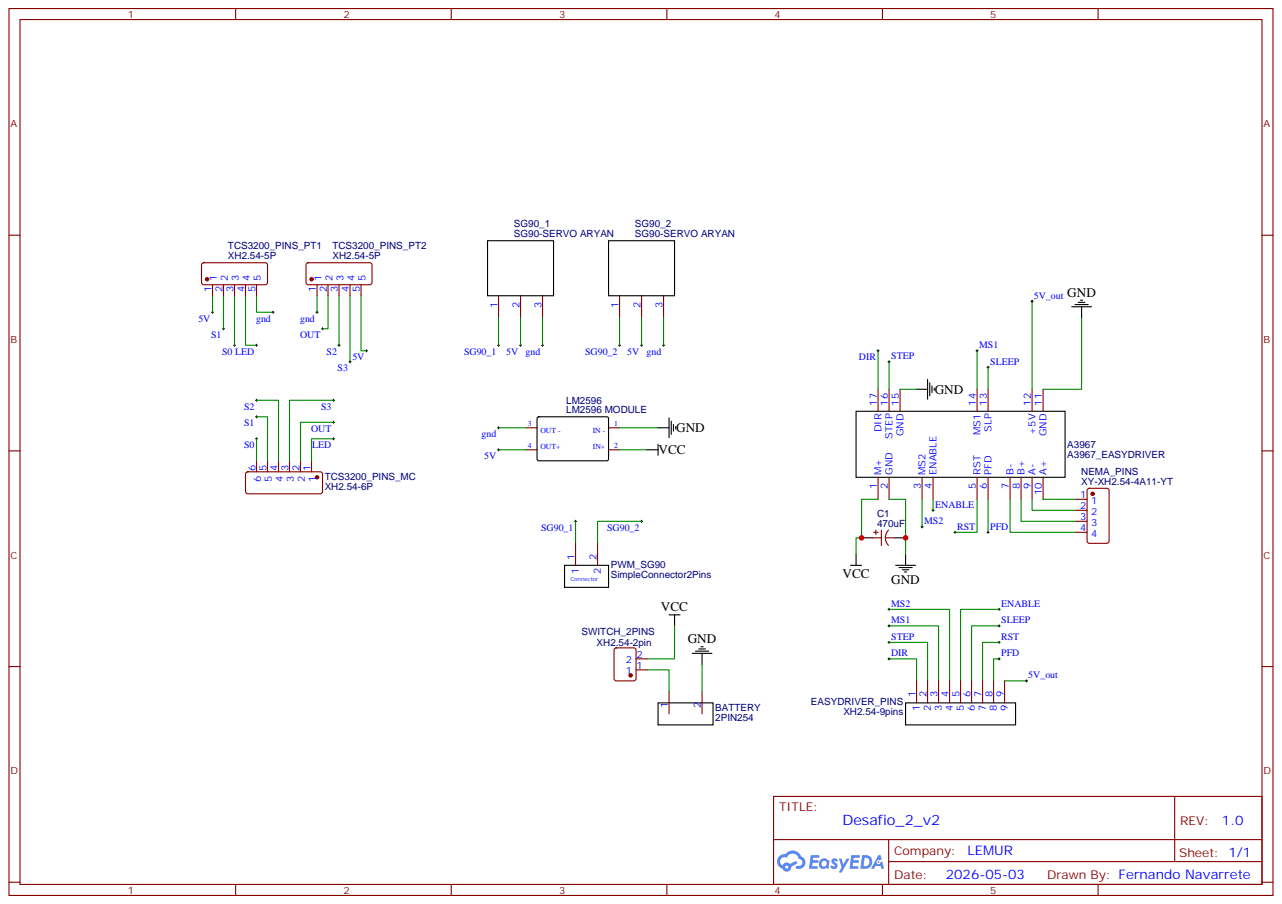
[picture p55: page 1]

Drawn By: Fernando Navarrete

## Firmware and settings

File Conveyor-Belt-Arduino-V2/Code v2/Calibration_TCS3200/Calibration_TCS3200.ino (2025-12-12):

#include <Arduino.h>

// ====== Pines TCS3200 (GY-31) ======
const int S0 = A0;
const int S1 = A1;
const int S2 = A2;
const int S3 = A3;
const int OUT_PIN = 2;  // Salida de frecuencia

volatile unsigned long pulseCount = 0;

// --- ISR: contar flancos del OUT ---
void countPulse() {
  pulseCount++;
}

// Tiempo de muestreo en milisegundos
const unsigned long SAMPLE_MS = 100;

// --- Medición de frecuencia (Hz) ---
unsigned int measureFreq(uint8_t ch) {
  // Selección de filtro de color
  switch (ch) {
    case 0: digitalWrite(S2, LOW);  digitalWrite(S3, LOW);  break;  // R
    case 1: digitalWrite(S2, HIGH); digitalWrite(S3, HIGH); break;  // G
    case 2: digitalWrite(S2, LOW);  digitalWrite(S3, HIGH); break;  // B
  }

  pulseCount = 0;
  unsigned long t0 = millis();
  while (millis() - t0 < SAMPLE_MS) {
    // conteo dentro de la ventana temporal
  }
  unsigned int freq = (unsigned int)((pulseCount * 1000UL) / SAMPLE_MS);
  return freq;
}

void setup() {
  Serial.begin(115200);

  pinMode(S0, OUTPUT);
  pinMode(S1, OUTPUT);
  pinMode(S2, OUTPUT);
  pinMode(S3, OUTPUT);
  pinMode(OUT_PIN, INPUT);

  // Configuración de escala (~20%)
  digitalWrite(S0, HIGH);
  digitalWrite(S1, LOW);

  attachInterrupt(digitalPinToInterrupt(OUT_PIN), countPulse, RISING);

  Serial.println("===== Calibración del Sensor TCS3200 =====");
  Serial.println("Coloca un objeto NEGRO o superficie OSCURA debajo del sensor.");
  Serial.println("Luego, presiona cualquier tecla en el monitor serie.");
  Serial.println();
}

void loop() {
  if (Serial.available()) {
    Serial.read(); // limpiar buffer

    // Medición para cada color
    unsigned int fR = measureFreq(0);
    unsigned int fG = measureFreq(1);
    unsigned int fB = measureFreq(2);

    Serial.println("Lectura actual:");
    Serial.print("R: "); Serial.print(fR);
    Serial.print(" | G: "); Serial.print(fG);
    Serial.print(" | B: "); Serial.println(fB);

    Serial.println("\nCambia el color de referencia (oscuro o blanco)");
    Serial.println("y presiona otra tecla para medir nuevamente.\n");

    delay(1000);
  }
}

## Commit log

2025-10-11 Assembly Manuals EN/ES add
2025-12-10 Update CAD Files and Electronic diagram
    [Apoyo pared lateral.f3d, Apoyo pared lateral.step, Baby REPO.f3z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]
2025-12-10 V1 folder
    [Apoyo pared lateral.f3d, Apoyo pared lateral.step, Baby REPO.f3z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]
2025-12-27 Conveyor Belt Arduino DIY v1 finished
2025-12-27 Conveyor Belt Arduino DIY Multimedia/as_built
2026-05-23 Conveyor Belt Arduino V2 in process
2026-05-23 Conveyor Belt Arduino V2 Assembly_Manual Demo finished
2026-06-11 New files V2 and Demo Assembly manual
2026-06-11 Update CAD files V2 and README.md
    [Apoyos_Laterales_Dobles.f3z, Apoyos_Laterales_Dobles.step, Battrey Case 16850x3.f3d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]
2026-06-11 ⚙️ Mecatrónica: Migración de archivos mecánicos masivos STEP a Git LFS
2026-06-11 Update CAD files LFS Tracking
    [Apoyo pared lateral.f3d, Apoyo pared lateral.step, Baby REPO.f3z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]

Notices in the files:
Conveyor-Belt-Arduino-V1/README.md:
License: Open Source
